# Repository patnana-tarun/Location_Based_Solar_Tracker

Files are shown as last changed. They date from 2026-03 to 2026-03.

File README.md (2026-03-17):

# 🌞 Location-Based Dual-Axis Solar Tracker

> **A professional, industrial-grade telemetry and control platform for solar tracking. This project combines high-performance STM32 firmware with astronomical algorithms to provide real-time GPS-driven positioning, active monitoring, and precision servo regulation.**



[]()
[]()

---

## 📖 Table of Contents

- [Project Overview](#-project-overview)
- [Hardware Specifications](#%EF%B8%8F-hardware-specifications)
- [Control & Safety Features](#-control--safety-features)
- [Dashboard Tech Stack](#-dashboard-tech-stack)
- [Installation & Setup](#-installation--setup)
- [Usage & Telemetry](#-usage--telemetry)
- [Folder Structure Guide](#%EF%B8%8F-folder-structure-guide)
- [Recommended Reading Flow](#%EF%B8%8F-recommended-reading-flow)

---

## 📝 Project Overview

Unlike traditional solar trackers that use light sensors (LDRs) and get confused by clouds, **this system calculates where the sun _should_ be** based on its exact GPS location and time. It uses the National Renewable Energy Laboratory (NREL) Solar Position Algorithm (SPA) to mathematically track the sun, ensuring reliable operation in all weather conditions.

Why this project?
- **Astronomical Precision:** Math-driven tracking instead of light-chasing.
- **Hardware Integration:** Drives two servos (azimuth and elevation) while monitoring current/voltage via an ADC.
- **Night Return:** Automatically rests at the sunrise angle when the sun sets.
- **Live Telemetry:** Sends live system data to a Real-Time Python/HTML Dashboard over UART.

---

## ⚙️ Hardware Specifications

The system is built on a modular architecture consisting of the following core components:

**Control & Processing**
- **Microcontroller:** STM32F401RE (ARM Cortex-M4 @ 84 MHz).
- **Timekeeping:** DS3231 High-Precision Real-Time Clock (RTC) via I2C.
- **Location:** NEO-6M GPS Module for real-time spatial coordinates via UART.
- **Telemetry:** High-speed UART broadcasting for real-time data ingestion.

**Actuation & Positioning**
- **Servos:** 2x MG995 or SG90 for Dual-Axis (Azimuth and Elevation) control.
- **Algorithm Output:** PWM generation mapped to 0–180° rotation limits.

**Sensing & Feedback**
- **Current Sensing:** ACS712 Hall-Effect sensor for RMS current measurement on the PV output.
- **Voltage Sensing:** Precision Resistor Voltage Divider to safely monitor PV voltage.
- **Display:** SSD1306 OLED (128x64) for localized status and parameter readouts.

---

## ✨ Control & Safety Features

- **Astronomical SPA Integration:** Implements Julian Day rendering and atmospheric refraction calculation to output exact solar positioning regardless of environmental light conditions.
- **Adaptive Smooth Actuation:** Step-looped rotational tracking with programmable delay insertion to prevent mechanical shock and high inrush currents on servo movement.
- **Intelligent Night Mode:** Automatically disables active tracking and regressions the array to sunrise coordinates when solar elevation drops below 0°.
- **System Calibration Mode:** Hardcoded step-through testing sequence at 10° intervals for precise initial calibration and mechanical limit verification.
- **Integrated Power Monitoring:** Real-time ADC polling to monitor generated power and voltage levels continuously.

---

## 💻 Dashboard Tech Stack

The Solar Tracker frontend is a lightweight telemetry dashboard designed for real-time data visualization via local WebSocket tunneling.

- **Backend Bridge:** Python 3 `websockets` and `pyserial` server to parse continuous `$TELEM` packets.
- **Frontend Markup:** Responsive HTML/JS UI.
- **Visualization:** Live numerical and state-based readouts (Azimuth, Elevation, Voltage, Current, Algorithm Accuracy Delta).
- **Validation Engine:** Built-in compiled NREL SPA logic to validate the microcontroller's math identically in real-time.

---

## 🚀 Installation & Setup

### Prerequisites
- [STM32CubeIDE](https://www.st.com/en/development-tools/stm32cubeide.html)
- Python 3.8+ (for dashboard)
- A connected STM32 NUCLEO-F401RE board

### Step 1: Clone the Repository
```bash
git clone https://github.com/patnana-tarun/Location_Based_Solar_Tracker.git
cd Location_Based_Solar_Tracker
```

### Step 2: Flash the Firmware
1. Open **STM32CubeIDE**.
2. Import the project from the `firmware/` directory.
3. Open `firmware/src/main_v6.c` and adjust `FIXED_LATITUDE` and `FIXED_LONGITUDE` if desired.
4. Build and flash the code to the STM32.

### Step 3: Launch the Dashboard
```bash
cd dashboard
pip install pyserial websockets
python server.py COM8  # Use your specific COM port (e.g., /dev/ttyUSB0 on Linux)
```
Then, exactly double-click `index.html` (or open it your favorite web browser) to view the live dashboard.

---

## 🛠️ Usage & Telemetry

**Data Output Format (STM32 to Dashboard)**
The dashboard expects a comma-separated `$TELEM` string from the STM32 via UART:
`$TELEM,YYYY-MM-DD,HH:MM:SS,LAT(N/S),LON(E/W),AZ,EL,SERVO_AZ,SERVO_EL,V,A,MODE*`

- **AZ/EL:** Calculated Astronomical Azimuth and Elevation
- **SERVO_AZ/EL:** Actual driven PWM servo angles
- **V/A:** Solar Panel Voltage and Current
- **MODE:** Current operational state (TRACKING, NIGHT, CALIBRATING)

---

## 🗂️ Folder Structure Guide

To keep the repository clean and professional, the project is organized into dedicated directories for firmware, hardware, software, and detailed documentation. 

```text
solar-tracker/
│
├── docs/                        ← Detailed project documentation
│   ├── project-overview.md      ← Deep-dive on why and how the tracker works
│   ├── hardware-architecture.md ← Explanation of electronics and BOM
│   ├── software-architecture.md ← Explanation of the firmware algorithms
│   ├── wiring-diagram.md        ← STM32 pin connections guide
│   ├── calibration.md           ← How to tune the servos and sensors
│   ├── troubleshooting.md       ← Common issues and solutions
│   └── reference_materials/     ← Original project reports & reviews (.docx/.pdf)
│
├── hardware/                    ← Physical build resources
│   ├── components-list.md       ← Comprehensive bill of materials (BOM)
│   ├── mechanical/              ← 3D models and chassis designs
│   ├── pcb/                     ← Custom board layouts
│   └── wiring/                  ← Circuit diagrams
│
├── firmware/                    ← STM32 Embedded C Code
│   ├── src/                     ← Main codebase (main_v6.c, driver files)
│   ├── config/                  ← IDE configurations
│   ├── stm32_project/           ← Complete STM32CubeIDE project workspace
│   └── README.md                ← Instructions on flashing the microcontroller
│
├── dashboard/                   ← PC Telemetry Software
│   ├── server.py                ← Python WebSocket & UART bridge
│   ├── index.html               ← Real-time browser UI
│   ├── spa.c / spa.h            ← Reference calculation files
│   └── README.md                ← Instructions for starting the dashboard
│
├── images/                      ← Visual resources for the docs
├── simulations/                 ← Math models or testing scripts
├── examples/                    ← Usage examples and logs
└── data/                        ← Stored telemetry data
```

---

## 🗺️ Recommended Reading Flow

If you are seeing this repository for the first time, we recommend following this path to understand everything quickly:

1. **[docs/project-overview.md](docs/project-overview.md):** Read this first. It explains the core concepts and the fundamental difference between GPS-based and Sensor-based tracking.
2. **[docs/hardware-architecture.md](docs/hardware-architecture.md):** Understand what components make up the physical device.
3. **[docs/software-architecture.md](docs/software-architecture.md):** Learn how the math in the firmware (the Solar Position Algorithm) operates.
4. **[docs/wiring-diagram.md](docs/wiring-diagram.md):** See how the STM32, servos, GPS, and RTC connect together.
5. **[firmware/README.md](firmware/README.md):** Follow these steps to compile and flash the code to your NUCLEO board.
6. **[dashboard/README.md](dashboard/README.md):** Learn how to launch the live telemetry visualization on your PC.

---

## 📜 License

This project is licensed under the **MIT License** — see [LICENSE](LICENSE) for full text.

The NREL Solar Position Algorithm (SPA) code in `dashboard/spa.c` and `dashboard/spa.h` is provided by the **National Renewable Energy Laboratory (NREL)** and is used in accordance with their terms.

---

*Built with ❤️ for EEE Tech Fair 2026*

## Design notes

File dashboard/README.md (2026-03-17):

# Solar Tracker Real-Time Dashboard

This is the Python-based real-time telemetry dashboard for the smart solar tracker. It reads `$TELEM` packets from the STM32 via USB/UART and hosts a local WebSocket server to stream the live data to a web browser interface.

## Requirements
- Python 3.8+
- `pyserial` and `websockets` libraries

## Execution Instructions

1. **Install dependencies:**
   Open your terminal in this directory and run:
   ```bash
   pip install pyserial websockets
   ```

2. **Start the server:**
   Connect your STM32 or FTDI adapter to your PC. Identify the COM port (e.g., `COM8` on Windows, `/dev/ttyUSB0` on Linux/Mac).
   
   Run the server using your specific port:
   ```bash
   python server.py COM8
   ```

3. **Open the Dashboard UI:**
   While the server is running, exactly double-click `index.html` (or open it your favorite web browser). The page will connect to the local server automatically and start displaying solar position, servo angles, and power metrics.

## Important Note

The file `spa_calc.exe` (and its source files `spa.c`, `spa.h`, `main.c`) is used internally by `server.py` to continuously validate the microcontroller's math against the National Renewable Energy Laboratory (NREL) reference algorithm. Do not delete it.

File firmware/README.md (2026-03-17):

# Firmware — Build and Flash Guide

This folder contains all the STM32 firmware source code for the Location-Based Solar Tracker.

---

## Which Firmware Version?

| File | Version | Description |
|---|---|---|
| `src/main.c` | **v6.0 (use this)** | Final version with Check Mode, unified OLED display, structured telemetry, compile-time RTC init |
| `src/main_v56_calibration.c` | v5.6 | Earlier version with calibration mode and 10° step testing. Use this to verify servo mechanicals. |

> **Start with `src/main.c` (v6.0) for normal use.**  
> Use `src/main_v56_calibration.c` if you need the more detailed calibration sweep.

---

## Prerequisites

1. Install **[STM32CubeIDE](https://www.st.com/en/development-tools/stm32cubeide.html)** (free, includes GCC compiler + debugger)
2. Install **STM32CubeF4 package** (STM32CubeIDE will prompt you on first use)
3. Connect the NUCLEO board to your PC with a Micro-USB cable (use the ST-Link USB port, not the morpho connector)

---

## Importing the Project

1. Open STM32CubeIDE
2. Go to `File → Import → General → Existing Projects into Workspace`
3. Browse to the `firmware/` folder
4. Select the project and click **Finish**

---

## Configuration (Before Building)

Open `firmware/src/main.c` and find the configuration section at the top of the file. Adjust these values for your location and use case:

```c
/* =================== DEMO MODE CONFIGURATION =================== */
#define DEMO_MODE 1              // Set to 0 for real tracking, 1 for demo/presentation

/* =================== LOCATION SOURCE (COMPILE-TIME) =================== */
// In DEMO_MODE=0, choose ONE:
#define USE_FIXED_LOCATION 1     // Use hardcoded lat/lon below
#define USE_GPS_LOCATION   0     // Use live GPS (requires NEO-6M module)

#define FIXED_LATITUDE  10.90    // Your latitude (positive = North)
#define FIXED_LONGITUDE 76.90    // Your longitude (positive = East)
#define FIXED_LAT_HEMI 'N'       // 'N' or 'S'
#define FIXED_LON_HEMI 'E'       // 'E' or 'W'

/* =================== NIGHT MODE CONFIGURATION =================== */
#define SUNRISE_HOUR 6           // Solar tracking starts at 6 AM
#define SUNSET_HOUR  18          // Solar tracking stops at 6 PM

/* =================== SMOOTH MOVEMENT =================== */
#define SMOOTH_STEP_SIZE  1.0f   // Degrees per step (smaller = smoother but slower)
#define SMOOTH_STEP_DELAY 40     // Milliseconds between steps

/* =================== DEFAULT TIMEZONE =================== */
#define DEFAULT_TIMEZONE 5.5f    // India = 5.5, UK = 0, US Eastern = -5
```

---

## Building the Firmware

1. Right-click the project in the Project Explorer
2. Click **Build Project**
3. Wait for `Build Finished` in the Console tab (should show 0 errors)

---

## Flashing to the Board

1. Connect the NUCLEO board via USB (ST-Link port)
2. Click the **Run** button (green play icon) or press `F11`
3. STM32CubeIDE will flash the firmware and start debugging
4. The OLED should show `Solar Tracker / v6.0 Ready` within a few seconds

**Alternative (command line):**
```bash
# Using OpenOCD (if installed separately)
openocd -f board/st_nucleo_f4.cfg -c "program Debug/firmware.elf verify reset exit"
```

---

## Serial Monitor / UART Debug

Connect a serial terminal to the NUCLEO's virtual COM port (appears as `COMx` on Windows, `/dev/ttyACM0` on Linux):

- **Baud rate:** 115200
- **Data bits:** 8
- **Parity:** None
- **Stop bits:** 1

The firmware prints detailed startup messages and `$TELEM` data every tracking cycle.

**Recommended terminals:**
- [PuTTY](https://www.putty.org/) (Windows)
- [Tera Term](https://ttssh2.osdn.jp/) (Windows)
- `screen /dev/ttyACM0 115200` (Linux/Mac)

---

## Required External Libraries

### SSD1306 OLED Driver (Included)

The `ssd1306.c` and `ssd1306.h` files provide:
- `SSD1306_Init(I2C_HandleTypeDef *i2c)` — Initialize the display
- `SSD1306_Clear()` — Clear the display buffer
- `SSD1306_DrawString(x, y, str)` — Draw text at a position
- `SSD1306_UpdateScreen()` — Push buffer to display

Place these in `firmware/src/` and add the path to your include directories in STM32CubeIDE.

---

## Common Compile Errors and Fixes

| Error | Fix |
|---|---|
| `ssd1306.h: No such file or directory` | Add `firmware/src` to include paths in project properties |
| `undefined reference to 'SSD1306_Init'` | Add `ssd1306.c` to the build (right-click → Add to Build) |
| `math.h function undefined` | Add `-lm` to linker flags (Project → Properties → C/C++ Build → Settings → Linker → Libraries) |

---

## Folder Structure

```
firmware/
├── src/
│   ├── main.c                    ← v6.0 final firmware
│   ├── main_v56_calibration.c    ← v5.6 calibration firmware
│   ├── ssd1306.c                 ← OLED driver implementation
│   └── ssd1306.h                 ← OLED driver header
└── config/
    └── STM32F401RETX_FLASH.ld    ← Linker script (flash execution)
```

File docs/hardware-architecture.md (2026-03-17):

# Hardware Architecture

This document describes the hardware design of the solar tracker — what each component does, why it was chosen, and how the pieces connect together.

---

## Block Diagram

```
                        ┌──────────────────────────────┐
                        │   STM32 NUCLEO-F401RE         │
                        │   (Cortex-M4, 84 MHz)         │
                        │                              │
 [NEO-6M GPS] ──UART1──►│ PA10 (RX)                    │
                        │                              │
 [DS3231 RTC] ──I2C1───►│ PB8 (SCL) PB9 (SDA)          │
 [SSD1306 OLED]─I2C1───►│                              │
                        │                              │
 [Solar Panel V]─ADC───►│ PA4 (ADC1_CH4)               │──PWM──► [Servo 1 - Azimuth]
 [ACS712 I_out]─ADC───►│ PA5 (ADC1_CH5)               │──PWM──► [Servo 2 - Elevation]
                        │                              │
 [PC / ST-Link] ─UART2─►│ PA2 (TX), PA3 (RX)           │
 [Check Button] ─GPIO──►│ PC13                         │
                        └──────────────────────────────┘
```

---

## Components In Detail

### 1. STM32 NUCLEO-F401RE (Main Microcontroller)

- **Core:** ARM Cortex-M4 at 84 MHz
- **Flash:** 512 KB, **SRAM:** 96 KB
- **Why chosen:** Widely available, affordable (~$15), supported by free STM32CubeIDE, has enough timers and UART ports for all peripherals
- **Built-in features used:** TIM2 for PWM, ADC1, I2C1, USART1, USART2, GPIO

---

### 2. NEO-6M GPS Module

- **Protocol:** UART at 9600 baud
- **Output:** NMEA 0183 sentences (GPRMC, GPGGA)
- **Accuracy:** ±2.5m position, ±1s time (after cold fix)
- **Why used:** GPS provides exact latitude, longitude, and UTC time — all three are needed for the solar position algorithm
- **Connection:** TX pin → NUCLEO PA10 (USART1 RX)
- **Note:** Cold start fix takes 30–90 seconds. The firmware falls back to a hardcoded location until a GPS fix is acquired.

**NMEA Sentences Parsed:**
- `$GPRMC` — Position, velocity, date, valid flag
- `$GPGGA` — Position, fix quality, number of satellites

---

### 3. DS3231 RTC Module

- **Protocol:** I2C at 400 kHz
- **Address:** 0x68
- **Accuracy:** ±2 ppm (about ±1 minute per year)
- **Backup battery:** Holds time indefinitely when board is powered off
- **Why used:** The solar algorithm needs accurate time. GPS time can take minutes to acquire. The RTC provides instant time on boot.
- **Initialization:** On first flash, the firmware sets the RTC from the compiler's `__DATE__` and `__TIME__` macros

---

### 4. SSD1306 OLED Display (128×64, I2C)

- **Protocol:** I2C (shared bus with DS3231)
- **Driver library:** Custom `ssd1306.c` / `ssd1306.h`
- **Display layout (4 lines at 16px spacing):**
  - Line 0: Date and time (DD/MM/YYYY HH:MM)
  - Line 1: GPS coordinates (LAT, LON)
  - Line 2: Azimuth and elevation (Az: XX El: XX)
  - Line 3: Mode string (DEMO / NIGHT / GPS TRACK / CHECK MODE)
- **Why needed:** Allows the user to view system status without connecting to a PC

---

### 5. Servo Motors (×2)

- **Type:** Standard PWM servo (MG995 recommended for structural use, SG90 for lightweight)
- **Control signal:** 50 Hz PWM
  - 500µs pulse → 0°
  - 1500µs pulse → 90°
  - 2500µs pulse → 180°
- **Timer:** TIM2 on STM32 (PA0 = CH1 = Azimuth, PA1 = CH2 = Elevation)
- **Servo 1 (Azimuth):** Rotates the panel horizontally — covers east to west
- **Servo 2 (Elevation):** Tilts the panel vertically — covers horizon to zenith
- **Angle ranges:**
  - Azimuth: 0–180° (maps to compass 90°–270°)
  - Elevation: 0–90°

**Smooth Movement:** The firmware moves servos in 1° steps with 40ms between each step. This prevents mechanical shock and reduces current spikes.

---

### 6. ACS712 Current Sensor (5A range)

- **Output:** Analog voltage, centered at 2.5V (zero current)
- **Sensitivity:** 185 mV/A
- **Connection:** Output → PA5 (ADC1 Channel 5)
- **Calibration:** At startup, the firmware samples 50 readings × 50 averages to determine the zero-current offset, correcting for sensor bias
- **Formula:** `current = (adc_voltage - 2.5V) / 0.185`

---

### 7. Voltage Divider (Solar Panel Voltage)

- **Components:** Two resistors — 100 kΩ (top) + 20 kΩ (bottom)
- **Scale factor:** 5× (allows measuring up to ~16.5V with 3.3V ADC)
- **Connection:** Midpoint → PA4 (ADC1 Channel 4)
- **Formula:** `panel_voltage = adc_voltage × 5.0`
- **Sampling:** 100 ADC readings averaged to reduce noise

---

### 8. Push Button (Check Mode)

- **Connection:** PC13 → Ground (active low, internal pull-up)
- **Function:** Triggers the Check Mode servo test sequence
  - Press once → servos move through: 0/0 → 180/0 → 180/90 → 90/90
  - Press again → exit Check Mode
  - Auto-timeout: 30 seconds

---

## Power Requirements

| Component | Typical Current |
|---|---|
| STM32 NUCLEO | ~100 mA |
| NEO-6M GPS | ~45 mA (acquisition), ~20 mA (tracking) |
| DS3231 RTC | < 1 mA |
| SSD1306 OLED | ~10 mA |
| SG90 Servo (×2) | ~100–300 mA each under load |
| ACS712 Sensor | ~10 mA |
| **Total (peak)** | **~800 mA @ 5V** |

> ⚠️ **Use a 5V, 2A power supply.** USB power banks with fast-charge may work but standard PC USB ports (500mA) are not sufficient when servos are under load.

---

## Safety Considerations

- **Servo stall:** Avoid commanding a servo to push against a physical end-stop. Set software angle limits (`AZIMUTH_MAX_ANGLE`, `ELEVATION_MAX_ANGLE`) before running.
- **Current sense disconnection:** Always calibrate the current sensor before connecting the solar panel load. The firmware performs auto-calibration at power-on.
- **Short circuit:** The voltage divider only measures; it does not power anything. Ensure correct resistor values to avoid exceeding the ADC's 3.3V input limit.
- **Cable management:** Servo cables should have enough slack to rotate the full range without pulling connections loose.

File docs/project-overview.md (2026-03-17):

# Project Overview — Location-Based Dual-Axis Solar Tracker

## What Problem Does This Solve?

Solar panels generate the most electricity when they directly face the sun. A fixed panel loses 30–50% of its potential energy because the sun moves across the sky throughout the day.

A **solar tracker** mechanically follows the sun, keeping the panel pointed directly at it. This project implements a dual-axis tracker (two degrees of freedom: left/right and up/down) controlled by a microcontroller that knows exactly where the sun is using **GPS and astronomical math**.

---

## Background and Motivation

This project was built for **EEE Tech Fair 2026** to demonstrate:
1. A practical application of embedded systems in renewable energy
2. An alternative to the common LDR-based approach
3. Integration of GPS, RTC, OLED, servo motors, ADC, and a PC dashboard into one system

---

## How Traditional Trackers Work (and Why We Didn't Do That)

Traditional solar trackers use **Light Dependent Resistors (LDRs)**:
- Four LDR sensors are placed at the corners of the panel
- The microcontroller compares readings and moves the panel toward the brighter side
- This is a **closed-loop feedback system**

**Problem with LDRs:**
- On cloudy or partly cloudy days, the sensors are fooled by diffuse light
- The system can oscillate ("hunt") when light is roughly equal on both sides
- Shadows from nearby objects confuse the sensors
- No memory — if the panel is moved to the wrong position it can't self-correct without light

**Our Approach:**
- Calculate the sun's exact azimuth and elevation using GPS coordinates + current time
- Drive the motors to the calculated position directly (open-loop with astronomical precision)
- Works in overcast conditions — the panel moves to where the sun IS, not where it's brightest
- Night mode and automatic dawn recovery built in

---

## Academic Context

This type of tracker is called a **predictive** or **model-based** solar tracker. It is more commonly used in commercial and utility-scale solar installations. The algorithm we use is based on the **Solar Position Algorithm (SPA)** developed by Ibrahim Reda and Afshin Andreas at the **National Renewable Energy Laboratory (NREL)** in 2003, which is the industry standard for solar position calculations.

References:
- Reda, I., Andreas, A. (2003). *Solar Position Algorithm for Solar Radiation Applications*. NREL/TP-560-34302.
- Mousazadeh, H. et al. (2009). *A review of principle and sun-tracking methods for maximizing solar systems output*. Renewable and Sustainable Energy Reviews.

---

## Project Timeline

| Milestone | Description |
|---|---|
| v1–v4 | Early prototypes, sensor testing, basic servo control |
| v5.6 | Full calibration mode, OLED working, GPS integration |
| v6.0 | Final version — RTC init from build time, Check Mode, unified OLED display, structured UART telemetry |
| Dashboard | Python WebSocket server + HTML UI with SPA cross-validation |

---

## What This Project Demonstrates

- Reading and parsing GPS NMEA sentences in bare-metal C
- I2C communication with DS3231 RTC and SSD1306 OLED
- PWM servo control with smooth stepping via TIM2
- 12-bit ADC for voltage and current measurement with averaging
- Astronomical computation (Julian Day, Hour Angle, Declination) on an embedded processor
- Structured UART telemetry protocol (`$TELEM` format)
- Python asyncio WebSocket server
- Real-time browser dashboard

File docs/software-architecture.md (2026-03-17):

# Software Architecture

This document describes how the firmware and PC dashboard software are structured, what each module does, and how data flows through the system.

---

## Overview

The software consists of two main parts:

1. **Firmware** — C code running on the STM32 microcontroller (bare-metal HAL)
2. **Dashboard** — Python backend + HTML/JS frontend running on a PC

```
┌──────────────────────────────────────────────────────┐
│                   FIRMWARE (STM32)                    │
│                                                      │
│  main()                                              │
│    ├── Initialization                                │
│    │     ├── HAL_Init()                              │
│    │     ├── Servo_Init()                            │
│    │     ├── ADC_Init()                              │
│    │     ├── SSD1306_Init()                          │
│    │     ├── DS3231_SetTime()                        │
│    │     └── Current sensor calibration             │
│    │                                                │
│    └── Main Loop (while 1)                          │
│          ├── CheckMode_CheckButton()                 │
│          ├── [if GPS mode] parse NMEA               │
│          ├── DS3231_GetTime()                        │
│          ├── calculateSolarPosition()                │
│          ├── Servo_SmoothMove() x2                  │
│          ├── ADC_ReadVoltage() + ADC_ReadCurrent()   │
│          ├── UART_SendTelemetry()                    │
│          └── OLED_DisplayUnified()                  │
└──────────────────────────────────────────────────────┘
                         │ UART $TELEM packets
                         ▼
┌──────────────────────────────────────────────────────┐
│              PC DASHBOARD (Python + HTML)             │
│                                                      │
│  server.py                                           │
│    ├── Reads UART (pyserial)                         │
│    ├── Parses $TELEM packets                         │
│    ├── Calls SPA executable (spa_calc.exe) for ref   │
│    ├── Calculates accuracy delta                     │
│    └── Broadcasts JSON over WebSocket (8765)         │
│                                                      │
│  index.html (browser)                               │
│    └── Receives WebSocket JSON → updates UI          │
└──────────────────────────────────────────────────────┘
```

---

## Firmware Modules

### `main.c` — Entry Point and Main Loop

The entire firmware is in a single `main.c` file for simplicity. It is divided into clearly labeled sections:

| Section | Purpose |
|---|---|
| Configuration macros | `DEMO_MODE`, `USE_GPS_LOCATION`, lat/lon constants |
| Structures | `DateTime`, `SolarPosition`, `RTC_Time` |
| DS3231 driver | `DS3231_GetTime()`, `DS3231_SetTime()`, `ParseCompileTime()` |
| UART helpers | `DBG()` for debug, `UART_SendTelemetry()` for structured output |
| OLED display | `OLED_DisplayUnified()` — single 4-line display function |
| Servo control | `Servo_Init()`, `Servo_SetAngle()`, `Servo_SmoothMove()` |
| ADC | `ADC_Init()`, `ADC_ReadVoltage()`, `ADC_ReadCurrent()` |
| GPS parser | `split_csv()`, `nmea_to_deg()`, `parse_rmc()`, `parse_gga()` |
| Solar algorithm | `getJulianDay()`, `calculateSolarPosition()` |
| Check mode | `CheckMode_CheckButton()`, `CheckMode_Process()` |
| `main()` | Init sequence + main tracking loop |

---

### Solar Position Algorithm

This is the mathematical heart of the firmware. It calculates where the sun is in the sky at any given time and location.

**Inputs:**
- `DateTime` struct (year, month, day, hour, minute, second)
- Latitude (degrees, positive north)
- Longitude (degrees, positive east)
- UTC timezone offset (e.g., India = +5.5)

**Outputs:**
- `azimuth` — compass direction of the sun (0° = North, 90° = East, 180° = South, 270° = West)
- `elevation` — angle above the horizon (0° = horizon, 90° = directly overhead)
- `zenith` — 90° − elevation

**Key Steps:**
1. Convert date/time to **Julian Day (JD)** — a continuous day count from a fixed epoch
2. Compute the sun's **geometric mean longitude (L)** and **mean anomaly (M)**
3. Compute the **equation of center (C)** — the difference between the mean and true position
4. Calculate sun's **right ascension (RA)** and **declination (δ)**
5. Compute the observer's **hour angle (HA)** using Greenwich Sidereal Time (GMST)
6. Compute **elevation** from spherical coordinate geometry
7. Apply **atmospheric refraction correction** (especially important near the horizon)
8. Compute **azimuth** from the elevation and hour angle

This algorithm is adapted from the NREL SPA and produces results accurate to within ±0.001° over a multi-century range.

---

### Servo Control

Servo movement is controlled via **TIM2 in PWM mode**:

```
TIM2 Configuration:
  Prescaler = 15 (÷16 from 16 MHz HSI → 1 MHz timer clock)
  Period = 19999 (20 ms period → 50 Hz servo frequency)

Pulse mapping:
  0°   → 500  µs → CCR = 500
  90°  → 1500 µs → CCR = 1500
  180° → 2500 µs → CCR = 2500
```

`Servo_SmoothMove()` increments the current angle by 1° per step, with a 40ms HAL_Delay between steps. This creates smooth motion and protects the mechanical assembly.

---

### GPS NMEA Parser

The GPS module sends NMEA sentences as ASCII text at 9600 baud. The parser uses interrupt-driven UART receive (`HAL_UART_Receive_IT`) to collect characters into a buffer.

When a newline is detected, the buffer is checked for:
- `$GPRMC` — extracts latitude, longitude, and validity flag
- `$GPGGA` — extracts latitude, longitude, and fix quality

The `nmea_to_deg()` function converts the NMEA `DDMM.MMMM` format to decimal degrees.

---

### Operating Modes

| Mode | Set By | Behavior |
|---|---|---|
| `DEMO_MODE 1` | `#define` | Simulates 24-hour cycle, fixed location, no GPS needed |
| `DEMO_MODE 0` + `USE_GPS_LOCATION 1` | `#define` | Waits for real GPS fix, uses live coordinates |
| `DEMO_MODE 0` + `USE_FIXED_LOCATION 1` | `#define` | Uses hardcoded `FIXED_LATITUDE/LONGITUDE` |
| `CALIBRATION_MODE 1` | `#define` | Steps servos 0→180° in 10° steps with 2s pauses |
| Check Mode | Button press | Tests full servo range, shows position on OLED |
| Night Mode | Auto (elevation < 0) | Returns to sunrise position, OLED shows "NIGHT" |

---

### Telemetry Format

Every tracking cycle, the firmware sends a telemetry line over UART2 (ST-Link virtual COM port). Format:

```
$TELEM,YYYY-MM-DD,HH:MM:SS,LAT(N/S),LON(E/W),AZ,EL,SERVO_AZ,SERVO_EL,V,A,MODE*
```

Example:
```
$TELEM,2026-01-07,10:30:00,10.900000N,76.900000E,147.23,54.88,113.9,54.9,5.12,0.340,DEMO*
```

| Field | Unit | Description |
|---|---|---|
| Date | YYYY-MM-DD | Current date |
| Time | HH:MM:SS | Current time |
| LAT | °N/S | GPS latitude |
| LON | °E/W | GPS longitude |
| AZ | ° | Calculated sun azimuth |
| EL | ° | Calculated sun elevation |
| SERVO_AZ | ° | Actual azimuth servo angle |
| SERVO_EL | ° | Actual elevation servo angle |
| V | V | Solar panel voltage |
| A | A | Solar panel current |
| MODE | string | Operating mode name |

---

## Dashboard Software

### `server.py` — Python WebSocket Server

The server does three things simultaneously:
1. **Reads** the STM32 UART output via `pyserial`
2. **Validates** the firmware's solar position against the NREL SPA C executable
3. **Broadcasts** a JSON payload to all connected browser clients over WebSocket (port 8765)

**Accuracy comparison:**
- If `|delta| < 0.5°` → "excellent"
- If `|delta| < 1.0°` → "good"
- Else → "poor"

### `index.html` — Browser Dashboard

A single-file HTML dashboard that:
- Connects to `ws://localhost:8765`
- Displays all telemetry fields in a formatted UI
- Updates in real time as packets arrive
- Shows SPA comparison and accuracy rating

### `spa.c` / `spa.h` — NREL SPA Reference Library

The official NREL Solar Position Algorithm in C. Used by the dashboard to provide a ground-truth solar position for comparison with the firmware's calculation. An executable wrapper (`main.c` → `spa_calc.exe`) accepts command-line arguments and prints results in `KEY=VALUE` format.

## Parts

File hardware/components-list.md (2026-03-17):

# Component List — Bill of Materials (BOM)

This is the complete list of components needed to build the solar tracker from scratch.

---

## Main Components

| # | Component | Specification | Qty | Purpose | Approx. Cost (INR) |
|---|---|---|---|---|---|
| 1 | **STM32 NUCLEO-F401RE** | ARM Cortex-M4, 84 MHz, 512KB Flash | 1 | Main microcontroller | ₹700–800 |
| 2 | **NEO-6M GPS Module** | 9600 baud UART, NMEA 0183 | 1 | Location and time source | ₹200–300 |
| 3 | **DS3231 RTC Module** | I2C, ±2 ppm accuracy, CR2032 battery | 1 | Real-time clock | ₹100–150 |
| 4 | **SSD1306 OLED Display** | 128×64 pixels, I2C, 0.96 inch | 1 | Status display | ₹150–200 |
| 5 | **Servo Motor #1 (Azimuth)** | MG995 (180°) or SG90 (lightweight) | 1 | Left/right panel rotation | ₹150–300 |
| 6 | **Servo Motor #2 (Elevation)** | MG995 (180°) or SG90 | 1 | Up/down panel tilt | ₹150–300 |
| 7 | **ACS712 Current Sensor** | 5A range, ±2.5V output | 1 | Panel current monitoring | ₹100–150 |
| 8 | **Resistor — 100kΩ** | ¼W, 1% tolerance | 1 | Voltage divider (top) | ₹5 |
| 9 | **Resistor — 20kΩ** | ¼W, 1% tolerance | 1 | Voltage divider (bottom) | ₹5 |
| 10 | **Small Solar Panel** | 5V–6V, 50–500mA | 1 | Demonstration load | ₹150–300 |
| 11 | **5V Power Supply** | ≥2A output, regulated | 1 | Powers servos + board | ₹150–200 |
| 12 | **Push Button (Momentary)** | Through-hole or breadboard | 1 | Check Mode trigger | ₹10–20 |
| 13 | **Breadboard** | 830-point or larger | 1 | Prototyping | ₹80–120 |
| 14 | **Jumper Wires** | Male-to-male and male-to-female | 1 set | Wiring | ₹50–80 |
| 15 | **CR2032 Battery** | 3V coin cell | 1 | RTC backup | ₹20–30 |

**Estimated Total: ₹2,000–3,000 (complete kit)**

> 💡 If you already have the NUCLEO board, everything else costs around ₹1,200–1,800.

---

## Component Descriptions and Specs

### STM32 NUCLEO-F401RE
- **Microcontroller:** STM32F401RE (ARM Cortex-M4)
- **Clock:** Up to 84 MHz
- **Flash:** 512 KB, SRAM: 96 KB
- **Peripherals used:** TIM2 (PWM), ADC1, I2C1, USART1, USART2, GPIO
- **Built-in:** ST-Link debugger/programmer, USB virtual COM port
- **Voltage:** 3.3V I/O logic

### NEO-6M GPS Module
- **Protocol:** UART, 9600 baud
- **Output:** NMEA 0183 sentences ($GPRMC, $GPGGA)
- **Channels:** 50 (can track 50 satellites)
- **Position accuracy:** ±2.5m CEP
- **Time accuracy:** 1µs (synchronized to GPS time)
- **Cold start time:** 27s typical, up to 90s
- **Operating voltage:** 3.3V (some modules have on-board regulators for 5V input)

### DS3231 RTC Module
- **Interface:** I2C (address 0x68)
- **Accuracy:** ±2 ppm (~1 minute/year)
- **Temperature-compensated oscillator:** Yes
- **Backup power:** CR2032 coin cell (holds time for years)
- **Operating voltage:** 3.3V–5.5V (3.3V recommended)

### SSD1306 OLED Display
- **Resolution:** 128 × 64 pixels (monochrome)
- **Interface:** I2C (address 0x3C or 0x3D)
- **Size:** 0.96 inch diagonal
- **Operating voltage:** 3.3V
- **Current draw:** ~10mA typical

### MG995 Servo Motor
- **Torque:** 9.4 kg·cm (4.8V), 11 kg·cm (6V)
- **Operating speed:** 0.17 s/60° (4.8V)
- **Angle range:** 0–180°
- **PWM frequency:** 50 Hz
- **Pulse range:** 500µs – 2500µs
- **Operating voltage:** 4.8V – 6V
- **Use for:** heavier panel mounts, outdoor builds

### SG90 Servo Motor (Lightweight alternative)
- **Torque:** 1.8 kg·cm (4.8V)
- **Angle range:** 0–180°
- **Use for:** lightweight panels, indoor demos, prototypes

### ACS712 Current Sensor (5A)
- **Output:** Analog voltage (2.5V = 0A, sensitivity 185mV/A)
- **Range:** ±5A
- **Bandwidth:** 80 kHz
- **Operating voltage:** 5V

### Voltage Divider Network
- **R1:** 100kΩ (from panel+ to ADC pin)
- **R2:** 20kΩ (from ADC pin to GND)
- **Scale factor:** ×5 → max measurable voltage = 16.5V

---

## Optional / Upgrade Components

| Component | Purpose |
|---|---|
| ESP8266 Wi-Fi module | Wireless UART bridge for dashboard |
| SD card module (SPI) | Log telemetry data locally |
| 18650 Li-ion cell + TP4056 charger | Power the tracker from the solar panel |
| 3D-printed mount | Professional enclosure for servos and panel |
| Custom PCB | Replace breadboard wiring with soldered board |

---

## Where to Buy (India)

- **Robu.in** — good range of servos, sensors, displays
- **Evelta Electronics** — STM32 boards and modules
- **Amazon.in** — GPS, RTC, OLED modules with next-day delivery
- **AliExpress** — cheapest prices if lead time allows

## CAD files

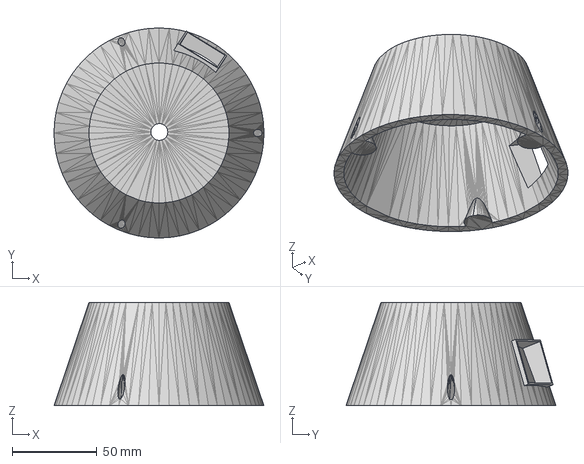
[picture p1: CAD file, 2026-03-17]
hardware/mechanical/BOTTOM SECTION.step
124.1 x 124.1 x 61.0 mm

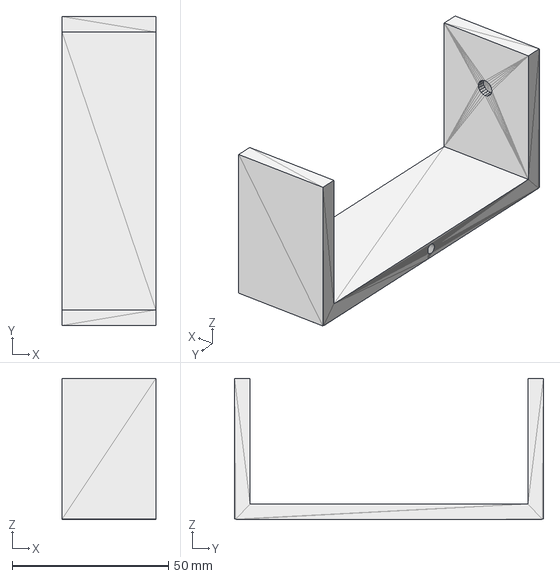
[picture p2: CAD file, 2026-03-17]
hardware/mechanical/ARM.step
30.0 x 98.8 x 45.1 mm

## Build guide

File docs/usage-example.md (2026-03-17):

# Usage Example — Sample Telemetry Output and Dashboard

This file shows what the system looks like in operation, including sample UART output and a description of the dashboard.

---

## Sample UART Output at Startup

Connect a serial terminal at **115200 baud** and press reset on the NUCLEO:

```
╔═══════════════════════════════════════════════╗
║  SOLAR TRACKER v6.0 - ENHANCED VERSION       ║
║  RTC Init + Location Control + Check Mode    ║
║  NUCLEO-F401RE @ 16 MHz HSI                  ║
╚═══════════════════════════════════════════════╝

Setting RTC from build time...
   RTC: 07/01/2026 10:00:00

Initializing Servos...
   Servos ready

Initializing ADC...
   ADC ready

Calibrating current sensor (disconnect load)...
   Zero offset: 0.0023A

Initializing OLED...
   OLED ready

Starting GPS receiver...
   GPS active

═══════════════════════════════════════════════
     DEMO MODE: Fixed Location                 
═══════════════════════════════════════════════
```

---

## Sample $TELEM Packets

After startup, the firmware sends one telemetry line per tracking cycle:

```
$TELEM,2026-01-07,06:00:00,10.900000N,76.900000E,109.45,2.15,19.5,2.2,5.10,0.120,DEMO*
$TELEM,2026-01-07,07:00:00,10.900000N,76.900000E,101.23,15.42,11.2,15.4,5.18,0.210,DEMO*
$TELEM,2026-01-07,08:00:00,10.900000N,76.900000E,93.44,28.78,3.4,28.8,5.21,0.280,DEMO*
$TELEM,2026-01-07,09:00:00,10.900000N,76.900000E,85.11,42.03,0.0,42.0,5.25,0.310,DEMO*
$TELEM,2026-01-07,12:00:00,10.900000N,76.900000E,173.88,67.12,83.9,67.1,5.50,0.455,DEMO*
$TELEM,2026-01-07,15:00:00,10.900000N,76.900000E,243.21,48.34,153.2,48.3,5.30,0.390,DEMO*
$TELEM,2026-01-07,17:00:00,10.900000N,76.900000E,263.54,18.22,173.5,18.2,5.11,0.185,DEMO*
$TELEM,2026-01-07,18:00:00,10.900000N,76.900000E,271.02,4.88,0.0,0.0,4.80,0.090,NIGHT*
```

### Understanding the Fields

```
$TELEM, 2026-01-07, 12:00:00, 10.90N, 76.90E, 173.88, 67.12, 83.9, 67.1, 5.50, 0.455, DEMO*
         └ date     └ time    └lat    └lon    └sun_az └sun_el └sv_az └sv_el └V   └A    └mode
```

| Field | Meaning |
|---|---|
| `2026-01-07` | Date |
| `12:00:00` | Time |
| `10.90N` | Latitude 10.90° North |
| `76.90E` | Longitude 76.90° East |
| `173.88` | Sun's calculated azimuth (°) |
| `67.12` | Sun's calculated elevation (°) |
| `83.9` | Servo 1 (Azimuth) actual angle (°) |
| `67.1` | Servo 2 (Elevation) actual angle (°) |
| `5.50` | Solar panel voltage (V) |
| `0.455` | Solar panel current (A) |
| `DEMO` | Operating mode |

---

## OLED Display Layout

At solar noon, the OLED shows:

```
┌──────────────────┐
│07/01/2026 12:00  │   ← Date and time from RTC
│10.90N  76.90E    │   ← GPS latitude and longitude
│Az:84  El:67      │   ← Current servo angles
│DEMO TRACK        │   ← Mode string
└──────────────────┘
```

---

## Starting the Dashboard

```bash
# Install dependencies (first time only)
pip install pyserial websockets

# Run the server (replace COM8 with your serial port)
cd dashboard
python server.py COM8

# Output when running:
# ═══════════════════════════════════════════
#    Solar Tracker WebSocket Server v1.0
#    Using Compiled NREL SPA Executable
# ═══════════════════════════════════════════
# ✓ Using SPA executable: ./spa_calc.exe
# ✓ WebSocket server running on ws://localhost:8765
# ✓ Connected to COM8
# ✓ Client connected (1 total)
```

Then open `dashboard/index.html` in your browser.

---

## Sample JSON Payload (WebSocket)

Each packet received by the browser looks like this:

```json
{
  "datetime": { "year": 2026, "month": 1, "day": 7, "hour": 12, "minute": 0, "second": 0 },
  "location":  { "latitude": 10.9, "longitude": 76.9, "ns": "N", "ew": "E", "source": "FIXED" },
  "firmware":  { "azimuth": 173.88, "elevation": 67.12 },
  "servo":     { "azimuth": 83.9,   "elevation": 67.1  },
  "power":     { "voltage": 5.50,   "current": 0.455   },
  "mode":      "DEMO",
  "spa":       { "azimuth": 174.01, "elevation": 67.08, "zenith": 22.92 },
  "delta":     { "azimuth": -0.13,  "elevation": 0.04,  "accuracy": "excellent" }
}
```

The `delta` field shows how close the firmware's calculation is to the NREL SPA reference. An `accuracy` of "excellent" means the error is less than 0.5°.

---

## Demo Mode Tips (Tech Fair / Presentation)

- Set `DEMO_MODE 1` in `main.c` — no GPS or RTC needed
- The demo simulates a 24-hour cycle at your hardcoded location
- Each "hour" advances after `DEMO_DELAY_MS` milliseconds (default 3000ms = 3 seconds per simulated hour)
- The panel will visibly sweep from east to west during the demo
- OLED and dashboard update throughout
- At "sunset" (hour 18), the panel returns to the sunrise position automatically

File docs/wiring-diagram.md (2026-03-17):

# Wiring Guide

This document provides the complete pin-by-pin wiring table for the solar tracker, plus safety tips.

---

## Quick Reference Pin Table

| Component | Component Pin | NUCLEO-F401RE Pin | Notes |
|---|---|---|---|
| **NEO-6M GPS** | TX | PA10 (USART1 RX) | 9600 baud |
| **NEO-6M GPS** | GND | GND | |
| **NEO-6M GPS** | VCC | 3.3V or 5V | Check your module's rating |
| **DS3231 RTC** | SCL | PB8 (I2C1_SCL) | 4.7kΩ pull-up to 3.3V |
| **DS3231 RTC** | SDA | PB9 (I2C1_SDA) | 4.7kΩ pull-up to 3.3V |
| **DS3231 RTC** | VCC | 3.3V | |
| **DS3231 RTC** | GND | GND | |
| **SSD1306 OLED** | SCL | PB8 (I2C1_SCL) | Shared bus with RTC |
| **SSD1306 OLED** | SDA | PB9 (I2C1_SDA) | Shared bus with RTC |
| **SSD1306 OLED** | VCC | 3.3V | |
| **SSD1306 OLED** | GND | GND | |
| **Servo 1 (Azimuth)** | Signal | PA0 (TIM2_CH1) | 50 Hz PWM |
| **Servo 1 (Azimuth)** | VCC | External 5V | Do NOT power from NUCLEO |
| **Servo 1 (Azimuth)** | GND | GND (common) | |
| **Servo 2 (Elevation)** | Signal | PA1 (TIM2_CH2) | 50 Hz PWM |
| **Servo 2 (Elevation)** | VCC | External 5V | Do NOT power from NUCLEO |
| **Servo 2 (Elevation)** | GND | GND (common) | |
| **ACS712 Current** | OUT | PA5 (ADC1_CH5) | Analog voltage output |
| **ACS712 Current** | VCC | 5V | |
| **ACS712 Current** | GND | GND | |
| **Voltage Divider** | Midpoint | PA4 (ADC1_CH4) | 100kΩ + 20kΩ to panel |
| **Push Button** | Pin 1 | PC13 | |
| **Push Button** | Pin 2 | GND | Uses internal pull-up |
| **PC (Debug/Telemetry)** | USB | CN1 (ST-Link USB) | UART2 on PA2/PA3 |

---

## I2C Bus Note

The DS3231 RTC and SSD1306 OLED share the same I2C1 bus (PB8/PB9). This works because they have different I2C addresses:
- DS3231: `0x68`
- SSD1306: `0x3C`

Both devices must have **4.7kΩ pull-up resistors** from SDA and SCL to 3.3V. Many breakout boards already include these. If your OLED or RTC module does not have them built in, add them externally.

---

## Servo Power Note

> ⚠️ **Critical:** Servos draw significant current under load (100–500mA each). Do NOT power them from the NUCLEO's 5V or 3.3V pins. Use a dedicated 5V power supply.

Connect the power supply and the NUCLEO to a **common ground**. The servo signal wire connects to the STM32 GPIO pin only (signal is 3.3V logic, which works with standard servos).

---

## Voltage Divider for Panel Voltage Measurement

Build a simple voltage divider with two resistors:

```
Solar Panel (+) ─── 100kΩ ─── PA4 (ADC) ─── 20kΩ ─── GND
```

This divides the panel voltage by 5. So a 15V panel appears as 3.0V at the ADC (within the 3.3V limit).

Maximum measurable voltage = 3.3V × 5 = **16.5V**

---

## GPS Module Note

The NEO-6M GPS module requires a **clear view of the sky** for a valid fix. Indoors, you will likely not get a fix. The firmware handles this gracefully — it uses the hardcoded fallback location until a valid GPS reading arrives.

After power-on, allow **30–90 seconds** for the first fix. Subsequent fixes (warm start) are much faster.

---

## Wiring Diagram (ASCII Schematic)

```
                      ┌─────────────────────────────────┐
External 5V ─────────► VCC (servos)                    │
                      │                                 │
                      │  NUCLEO-F401RE                  │
             PA0 ────►  Sig ─ [Servo 1 Azimuth]        │
             PA1 ────►  Sig ─ [Servo 2 Elevation]      │
                      │                                 │
           PA10 ──────  ◄─ TX [NEO-6M GPS]             │
                      │                                 │
    PB8 (SCL) ────────  ─ SCL ─┬─ [DS3231]             │
    PB9 (SDA) ────────  ─ SDA ─┘   [SSD1306 OLED]      │
                      │                                 │
     PA4 ─── midpoint ─ [100k─V_panel] [20k─GND]       │
     PA5 ◄─ OUT ─ [ACS712] ─ VCC=5V                    │
                      │                                 │
    PC13 ◄── [Button] ─── GND                          │
                      └─────────────────────────────────┘
```

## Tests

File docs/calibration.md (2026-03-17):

# Calibration Guide

Calibration ensures that the servo motors move to the correct physical angles and that the current sensor reads zero accurately. This should be done whenever you assemble a new unit or swap servos.

---

## Step 1 — Current Sensor Auto-Calibration (Automatic)

The firmware performs this automatically at every power-on.

1. Power on the board **without connecting any load** to the solar panel terminals
2. Wait for the OLED to show `Solar Tracker / v6.0 Ready`
3. The firmware takes **50 samples × 50 readings** over ~3 seconds
4. It computes and stores a `current_zero_offset` value
5. All future current readings subtract this offset

> 💡 If the current always reads non-zero with no load connected, check that the ACS712 VCC is exactly 5.0V. Fluctuating supply voltage causes calibration drift.

---

## Step 2 — Servo Mechanical Calibration (CALIBRATION_MODE)

This mode lets you visually verify that the servos move correctly before attaching the solar panel.

### How to Enable Calibration Mode

Open `firmware/src/main.c` and change this line:

```c
#define CALIBRATION_MODE 0    // Change to 1
```

**Re-build and flash** the firmware.

### What Calibration Mode Does

The servo runs through this automated sequence:

| Test | Action |
|---|---|
| **TEST 1: Azimuth 0→180°** | Steps azimuth servo from 0° to 180° in 10° increments |
| **TEST 2: Elevation 0→90°** | Steps elevation servo from 0° to 90° in 10° increments |
| **TEST 3: Sun Positions** | Moves to Sunrise → Morning → Noon → Afternoon → Sunset |
| **Return Home** | Returns to sunrise position (Az=30°, El=10°) |

At each step:
- The servo moves smoothly (0.5°/step, 40ms delay — very slow and gentle)
- A **2-second pause** occurs so you can observe and measure the angle
- The OLED displays the current angle
- UART prints the angle to your serial monitor

### What to Check During Calibration

For each position:
- ✅ Does the servo move to the expected physical angle?
- ✅ Is there any mechanical binding or grinding?
- ✅ Are the wires long enough to not pull at the extremes?
- ✅ No mechanical "end stop" hitting at 0° or 180°?

### After Calibration

If the mechanical angles look correct, set the mode back to normal:

```c
#define CALIBRATION_MODE 0
```

If the servo isn't at the expected angle, you may need to:
- Adjust the `SERVO_MIN_PULSE` / `SERVO_MAX_PULSE` values
- Trim the servo horn mounting angle
- Add a mechanical offset to your mount

---

## Step 3 — Check Mode (Runtime Test)

Without reflashing, you can test the servo range at any time using the **hardware button** on PC13.

### How to Use Check Mode

1. Power on the board normally (tracking mode)
2. Press the user button once
3. The OLED displays `CHECK MODE` and the servos run:
   - Move to **0°, 0°** (home)
   - Move azimuth to **180°**
   - Move elevation to **90°**
   - Return to **neutral (90°, 90°)**
4. The OLED shows the current position and GPS/time info
5. Press the button again (or wait 30 seconds) to exit back to tracking

---

## Configurable Parameters Summary

| Parameter | Default | File | Description |
|---|---|---|---|
| `DEMO_MODE` | `1` | `main.c` | `1` = simulation, `0` = real tracking |
| `CALIBRATION_MODE` | `0` | `main.c` | `1` = enable calibration sweep |
| `FIXED_LATITUDE` | `10.90` | `main.c` | Fallback latitude (decimal degrees) |
| `FIXED_LONGITUDE` | `76.90` | `main.c` | Fallback longitude (decimal degrees) |
| `DEFAULT_TIMEZONE` | `5.5` | `main.c` | UTC offset (India = 5.5) |
| `SUNRISE_HOUR` | `6` | `main.c` | Hour to exit night mode |
| `SUNSET_HOUR` | `18` | `main.c` | Hour to enter night mode |
| `SUNRISE_AZIMUTH_POS` | `30.0°` | `main.c` | Azimuth parked position at night |
| `SUNRISE_ELEVATION_POS` | `10.0°` | `main.c` | Elevation parked position at night |
| `SMOOTH_STEP_SIZE` | `1.0°` | `main.c` | Step size for smooth servo movement |
| `SMOOTH_STEP_DELAY` | `40 ms` | `main.c` | Delay between smooth steps |
| `SERVO_MIN_PULSE` | `500 µs` | `main.c` | PWM pulse for 0° position |
| `SERVO_MAX_PULSE` | `2500 µs` | `main.c` | PWM pulse for 180° position |

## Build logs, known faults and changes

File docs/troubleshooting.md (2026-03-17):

# Troubleshooting Guide

This guide covers the most common problems you might encounter and how to fix them.

---

## Hardware Issues

### OLED not displaying anything

| Possible Cause | Fix |
|---|---|
| Wrong I2C address | Check if your OLED uses `0x3C` or `0x3D`. Update `ssd1306.h` |
| Missing pull-up resistors | Add 4.7kΩ from SDA and SCL to 3.3V |
| Loose I2C wires | Reseat PB8 (SCL) and PB9 (SDA) connections |
| OLED powered from wrong pin | Use 3.3V pin, not 5V — SSD1306 is a 3.3V device |

---

### Servos not moving / jittering

| Possible Cause | Fix |
|---|---|
| Powered from STM32 5V pin | Use external 5V ≥2A supply |
| Incorrect PWM frequency | Verify TIM2 prescaler produces 50 Hz (1 MHz / 20000 = 50 Hz) |
| Wrong signal pin | Use PA0 for Servo 1, PA1 for Servo 2 |
| Ground not shared | Connect GND of external supply to NUCLEO GND |

---

### GPS not getting a fix indoors

This is normal. GPS requires line-of-sight to satellites.

- Test near a window or outside
- The firmware uses the hardcoded `FIXED_LATITUDE/LONGITUDE` automatically when no fix is available
- After power-on, allow 30–90 seconds outdoors for the first fix
- Check UART debug output — it will print GPS status messages

---

### UART debug output showing garbage / wrong characters

| Possible Cause | Fix |
|---|---|
| Wrong baud rate in terminal | Set serial monitor to **115200 baud, 8N1** |
| Wrong COM port | Check Device Manager for the ST-Link virtual COM port |
| STM32CubeIDE monitor open | Close CubeIDE's serial view before using another terminal |

---

### Current sensor always reads high or negative

| Possible Cause | Fix |
|---|---|
| Load connected during calibration | Power on with nothing connected to the current sense path |
| ACS712 supply not 5.0V | Verify VCC is exactly 5V — use a multimeter |
| Wrong sensitivity constant | 5A module uses 185mV/A, 20A uses 100mV/A, 30A uses 66mV/A |

---

## Firmware / Software Issues

### STM32CubeIDE build error: "ssd1306.h not found"

The SSD1306 OLED driver header is not automatically included. Add the path:
1. Right-click the project → Properties → C/C++ Build → Settings → Include paths
2. Add `../Core/Inc` (or wherever you placed ssd1306.h)

---

### Firmware flashes successfully but nothing happens

1. Check the OLED — if blank, the code might be stuck in `Error_Handler()`
2. Open serial terminal at **115200 baud** — debug messages appear there
3. Common culprit: I2C bus hanging because a device is not responding. Disconnect OLED or RTC and try again.

---

### Solar position looks wrong / panel points away from sun

1. Verify `FIXED_LATITUDE` and `FIXED_LONGITUDE` match your actual location
2. Confirm `DEFAULT_TIMEZONE` is correct (India = `5.5`, UK = `0`, US Eastern = `-5`)
3. Make sure the DS3231 has the correct time — check UART output for the RTC init line
4. Verify the servo mechanical orientation matches the software's assumption:
   - Servo 1 (Azimuth) 0° = East, 90° = South, 180° = West (northern hemisphere)
   - Servo 2 (Elevation) 0° = Horizon, 90° = Zenith

---

### Python server.py error: "SPA executable not found"

The NREL SPA needs to be compiled first:

```bash
cd dashboard
gcc -o spa_calc spa.c main.c -lm
```

On Windows, use MinGW:
```bash
gcc -o spa_calc.exe spa.c main.c -lm
```

---

### Python server.py error: "No module named serial"

Install the required packages:
```bash
pip install pyserial websockets
```

---

### WebSocket dashboard not updating

1. Confirm `server.py` is running and shows `WebSocket server running on ws://localhost:8765`
2. Check the browser console (F12) for WebSocket connection errors
3. Ensure the STM32 is sending `$TELEM` lines — check in a serial terminal first
4. Try refreshing the browser page

---

## Getting Help

If your issue is not listed here:
1. Check the UART debug output — the firmware prints detailed status at startup
2. Enable `CALIBRATION_MODE 1` to isolate servo issues
3. Open an issue on the GitHub repository with:
   - Your wiring setup (or a photo)
   - The UART debug output from serial monitor
   - Which firmware version you are using (`v5.6` or `v6.0`)

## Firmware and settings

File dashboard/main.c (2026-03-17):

#include <stdio.h>
#include <stdlib.h>
#include "spa.h"

int main(int argc, char *argv[])
{
    if (argc != 9) {
        fprintf(stderr, "Usage: %s <year> <month> <day> <hour> <minute> <second> <lat> <lon>\n", argv[0]);
        fprintf(stderr, "Example: %s 2026 1 7 12 0 0 12.9716 77.5946\n", argv[0]);
        return 1;
    }

    spa_data spa;

    /* Parse command-line arguments */
    spa.year   = atoi(argv[1]);
    spa.month  = atoi(argv[2]);
    spa.day    = atoi(argv[3]);
    spa.hour   = atoi(argv[4]);
    spa.minute = atoi(argv[5]);
    spa.second = atof(argv[6]);

    /* Location */
    spa.latitude  = atof(argv[7]);
    spa.longitude = atof(argv[8]);
    spa.timezone  = 5.5;
    spa.elevation = 900;

    /* Environment */
    spa.pressure    = 1013.25;
    spa.temperature = 27;

    /* Other required fields */
    spa.delta_ut1 = 0;
    spa.delta_t   = 69.0;
    spa.slope     = 0;
    spa.azm_rotation = 0;
    spa.atmos_refract = 0.5667;

    spa.function = SPA_ZA;  // Calculate zenith and azimuth only

    int result = spa_calculate(&spa);

    if (result == 0)
    {
        // Output in easy-to-parse format
        printf("AZIMUTH=%.6f\n", spa.azimuth);
        printf("ELEVATION=%.6f\n", 90.0 - spa.zenith);
        printf("ZENITH=%.6f\n", spa.zenith);
    }
    else
    {
        fprintf(stderr, "SPA_ERROR=%d\n", result);
        return 1;
    }

    return 0;
}

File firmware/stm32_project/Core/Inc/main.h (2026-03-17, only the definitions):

#define B1_Pin GPIO_PIN_13
#define B1_GPIO_Port GPIOC
#define LD2_Pin GPIO_PIN_5
#define LD2_GPIO_Port GPIOA

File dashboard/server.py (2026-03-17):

#!/usr/bin/env python3
"""
Solar Tracker Backend - Real-time UART to WebSocket Bridge
Calls compiled SPA executable for validation
"""

import asyncio
import json
import serial
import subprocess
import os
from datetime import datetime
try:
    from websockets.server import serve
except ImportError:
    import websockets
    serve = websockets.serve
from pathlib import Path

# =================== SPA EXECUTABLE WRAPPER ===================
class SPACalculator:
    """Wrapper to call compiled SPA C program"""
    
    def __init__(self, exe_path=None):
        """Initialize with path to spa_calc executable"""
        if exe_path is None:
            if os.name == 'nt':  # Windows
                exe_path = "./spa_calc.exe"
            else:  # Linux/Mac
                exe_path = "./spa_calc"
        
        self.exe_path = exe_path
        
        if not os.path.exists(exe_path):
            raise FileNotFoundError(
                f"SPA executable not found: {exe_path}\n"
                f"Compile with: gcc -o {os.path.basename(exe_path)} spa.c main.c -lm"
            )
        
        print(f"✓ Using SPA executable: {exe_path}")
    
    def calculate(self, year, month, day, hour, minute, second, lat, lon):
        """
        Call SPA executable and parse output
        Args: year, month, day, hour, minute, second, lat, lon
        Returns: dict with azimuth, elevation, zenith
        """
        try:
            # Build command
            cmd = [
                self.exe_path,
                str(year),
                str(month),
                str(day),
                str(hour),
                str(minute),
                str(second),
                str(lat),
                str(lon)
            ]
            
            # Run subprocess
            result = subprocess.run(
                cmd,
                capture_output=True,
                text=True,
                timeout=5
            )
            
            if result.returncode != 0:
                raise RuntimeError(f"SPA calculation failed: {result.stderr}")
            
            # Parse output
            output = {}
            for line in result.stdout.strip().split('\n'):
                if '=' in line:
                    key, value = line.split('=')
                    output[key.strip()] = float(value.strip())
            
            return {
                'azimuth': round(output.get('AZIMUTH', 0.0), 2),
                'elevation': round(output.get('ELEVATION', 0.0), 2),
                'zenith': round(output.get('ZENITH', 0.0), 2)
            }
            
        except subprocess.TimeoutExpired:
            raise RuntimeError("SPA calculation timeout")
        except Exception as e:
            raise RuntimeError(f"SPA calculation error: {e}")

# =================== TELEMETRY PARSER ===================
def parse_telemetry(line):
    """
    Parse firmware telemetry line:
    $TELEM,YYYY-MM-DD,HH:MM:SS,LAT(N/S),LON(E/W),AZ,EL,SERVO_AZ,SERVO_EL,V,A,MODE*
    """
    if not line.startswith('$TELEM,'):
        return None
    
    try:
        parts = line.strip().rstrip('*').split(',')[1:]  # Skip $TELEM
        
        # Parse date/time
        date_parts = parts[0].split('-')
        time_parts = parts[1].split(':')
        
        # Parse location
        lat_str = parts[2]
        lon_str = parts[3]
        lat = float(lat_str[:-1])
        lon = float(lon_str[:-1])
        ns = lat_str[-1]
        ew = lon_str[-1]
        
        return {
            'datetime': {
                'year': int(date_parts[0]),
                'month': int(date_parts[1]),
                'day': int(date_parts[2]),
                'hour': int(time_parts[0]),
                'minute': int(time_parts[1]),
                'second': int(time_parts[2])
            },
            'location': {
                'latitude': lat,
                'longitude': lon,
                'ns': ns,
                'ew': ew,
                'source': 'GPS' if 'GPS' in parts[-1] else 'FIXED'
            },
            'firmware': {
                'azimuth': float(parts[4]),
                'elevation': float(parts[5])
            },
            'servo': {
                'azimuth': float(parts[6]),
                'elevation': float(parts[7])
            },
            'power': {
                'voltage': float(parts[8]),
                'current': float(parts[9])
            },
            'mode': parts[10].strip()
        }
    except (IndexError, ValueError) as e:
        print(f"Parse error: {e}")
        return None
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

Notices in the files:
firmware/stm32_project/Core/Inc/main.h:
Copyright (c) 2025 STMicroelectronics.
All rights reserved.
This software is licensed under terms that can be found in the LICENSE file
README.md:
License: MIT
